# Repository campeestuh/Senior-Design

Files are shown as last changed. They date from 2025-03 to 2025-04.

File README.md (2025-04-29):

Circuit Wiring:

Rotary Encoder   --> FREENOVE ESP32 WROOM
> CLK (Output A) --> Pin 4 
> DT  (Output B) --> Pin 5 
> SW  (Switch)   --> Pin 16 
>  +  (VCC)      --> 5V 
> GND            --> GND

LCD 
VCC                 --> 5V
SDA (Serial Data)   --> Pin 21
SCL (Serial Clock)  --> Pin 22
GND                 --> GND

Button 
GND    --> GND
Signal --> Pin 19

Harness
STEP/PUL    --> Pin 15
DIRECTION   --> Pin 16
ENABLE      --> 5V

AUGER 
STEP/PUL    --> Pin 13
DIRECTION   --> Pin 14
ENABLE      --> 5V

AUGER 2 
STEP/PUL    --> Pin 33
DIRECTION   --> Pin 32
ENABLE      --> 5V

TREADMILL
STEP/PUL    --> Pin 27
DIRECTION   --> Pin 25
ENABLE      --> 5V

Arduino IDE
Board: ESP32 Wrover Module
How to get ESP32 Board Support:
- Go to File > Preferences
- In "Additional Board Manager URLs" add this URL:
https://dl.espressif.com/dl/package_esp32_index.json
- Click OK and save
- 
Install LiquidCrystal Library by Adafruit

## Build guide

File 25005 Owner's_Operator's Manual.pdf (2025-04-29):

# Owner’s/Operator’s Manual for Rat Treadmill

### Instructions for Use, Maintenance, and Safety

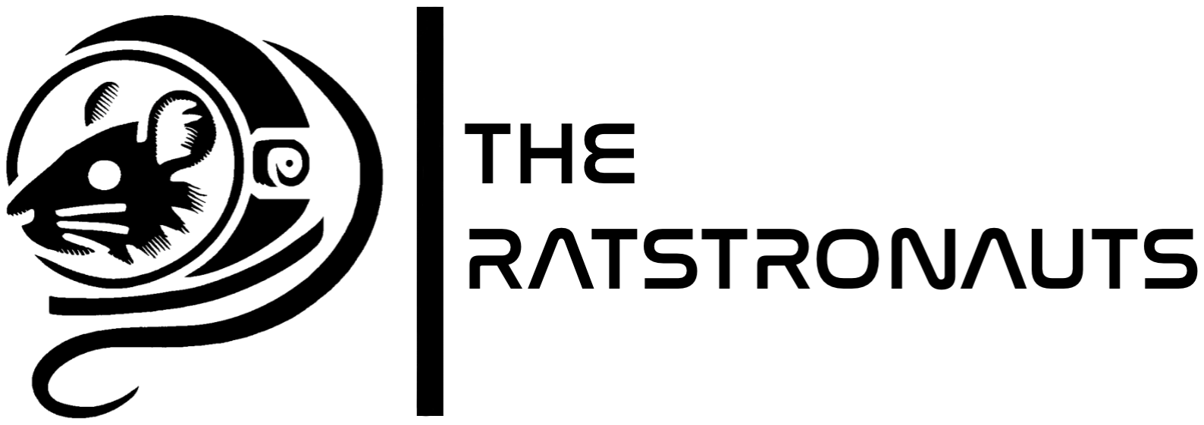
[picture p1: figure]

### Revision C

### Date of Issue: 05/07/2025

### Table of Contents

1. Introduction | 3
2. Safety Guidelines | 4
3. System Components | 7
4. Installation and Setup | 8
5. Operating Instructions | 10
6. Maintenance and Cleaning | 11
7. Technical Specifications | 16
8. Appendices | 17
9. Glossary | 18
10. Revision History | 19

### 1. Introduction

Welcome to the Owner’s/Operator’s Manual for the Rat Treadmill, a specialized research device designed to facilitate controlled exercise and locomotion studies in laboratory rodents. This treadmill’s advanced harness system, adjustable belt speed, and integrated data collection features enable researchers to study a range of physiological and behavioral parameters under standardized, reproducible conditions. Whether you are investigating muscle function, bone density changes, or aerobic capacity, the Rat Treadmill is engineered to help you gather accurate and consistent data while maintaining high standards of animal welfare.

This manual provides comprehensive guidance on setting up, operating, and maintaining the Rat Treadmill to ensure optimal performance and reliability. You will find safety instructions, technical specifications, and best practices for routine and preventative maintenance. Adherence to these guidelines not only helps protect the animals and operators but also contributes to the integrity and repeatability of your research findings.

By familiarizing yourself with the contents of this manual, you will gain an understanding of:

1. Safe Operation: Essential safety measures to protect both lab personnel and animals, including correct harness usage and emergency stop procedures.
2. Installation and Setup: Step-by-step instructions on how to calibrate and prepare the treadmill for use.
3. Daily Use and Study Protocols: Best practices for monitoring the animal’s condition and adjusting exercise parameters
4. Maintenance and Troubleshooting: Guidelines for regular cleaning, inspection, and repairs to maintain accuracy, prolong the lifespan of the equipment, and reduce downtime.

Please read this manual thoroughly before using the Rat Treadmill and keep it readily available for reference. Together, we can uphold the highest standards of care, safety, and scientific rigor in every research endeavor.

### 2. Safety Guidelines

- General Safety Reminder
- Although the Rat Treadmill is designed for ease of operation, safety must remain a priority. Only handle the treadmill by the areas that are color-coded in blue, as these sections are specifically intended for user interaction. Avoid touching or bypassing any other parts—particularly those marked with warning labels or guarded compartments—while the device is running. If you need to load or handle the aggregate, use a suitable respirator to protect against airborne particles and use the treadmill in a suitable environment. Always power down and wait for all motion to stop before clearing any obstructions or performing any maintenance tasks.
- Warnings and Precautions
- Proper Harness Use: Always ensure the harness is correctly fitted to the animal before operation. A loose or poorly adjusted harness can lead to injury or compromised research data. If in doubt, consult the harness fitting guidelines in this manual.
- Preventing Aerosolization of Regolith: Handle regolith gently and within a fume hood to minimize dust generation. A fume hood is required for usage of the system with aggregate. Avoid shaking, pouring, or dumping regolith in a way that creates airborne particles.
- Emergency Stop and Safety Features
- Unlike many traditional machines, the Rat Treadmill’s emergency stop (E-stop) feature initiates a gradual deceleration rather than an immediate halt. This prevents sudden jolts or stress on the rat, helping maintain its well-being during unexpected stops. Once the E-stop is engaged, the harness system automatically lifts the rat slightly above the belt and then sets the rat back down, ensuring the animal is safely out of contact with any moving parts.
- To further protect users and animals, all approved interaction points are color-coded in blue. Areas prone to pinch or crush injuries are equipped with warning decals and protective grates/covers, discouraging contact with moving mechanisms. Always avoid reaching into any section not marked in blue, and do not bypass guards or safety covers.
- Warning Decals (ISO 7010)
- P015 – No reaching in

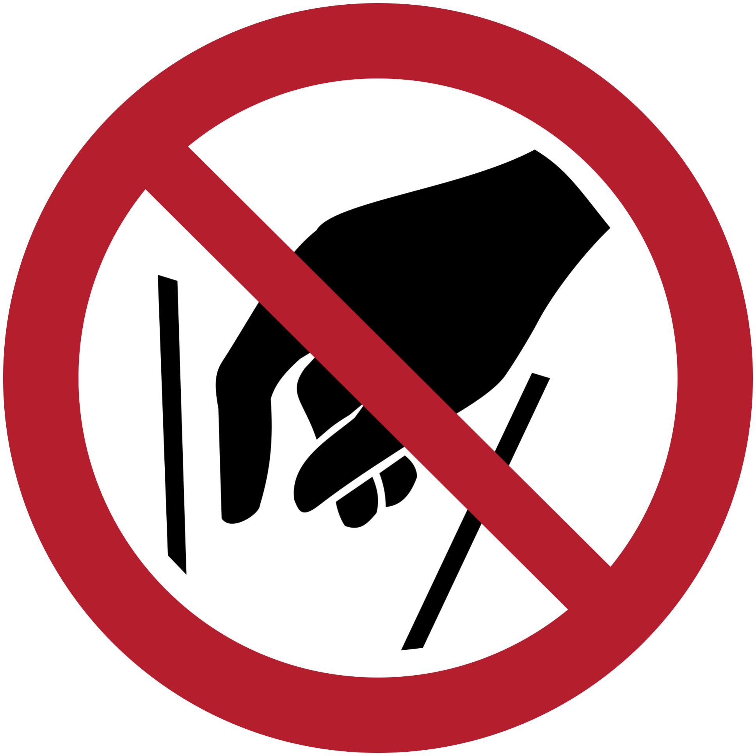
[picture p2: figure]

- Aggregate used in the treadmill may collect or clump in the hoppers, especially during heavy or prolonged use. While it might be tempting to manually guide or clear these accumulations, doing so places hands and fingers at risk of being trapped or pinched by the moving mechanical components.
- Do not insert hands, fingers, or tools into the hopper area while the treadmill is running. Always power down the treadmill before attempting any maintenance or cleaning.
- If you observe a clog or excessive buildup of aggregate, refer to the “Maintenance and Cleaning” section of this manual for instructions on safely clearing the blockage.
- P016 – Do not spray with water

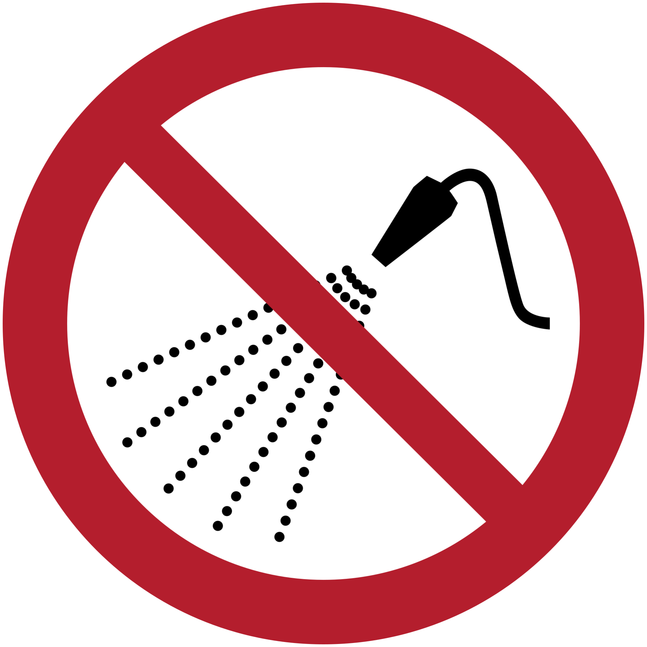
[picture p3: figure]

- Spraying or misting water can cause the aggregate to clump, disrupting the treadmill’s functionality and potentially damaging seals, leading to mechanical failure.
- Do not spray or apply water in or around the treadmill. Keeping the system dry is essential to maintain proper operation and prolong equipment life.
- If dust generation is a concern, operate the treadmill inside a fume hood. This ensures both operator safety and the prevention of moisture-related damage to the system.
- W024 – Crushing of hands/Danger of crush injuries

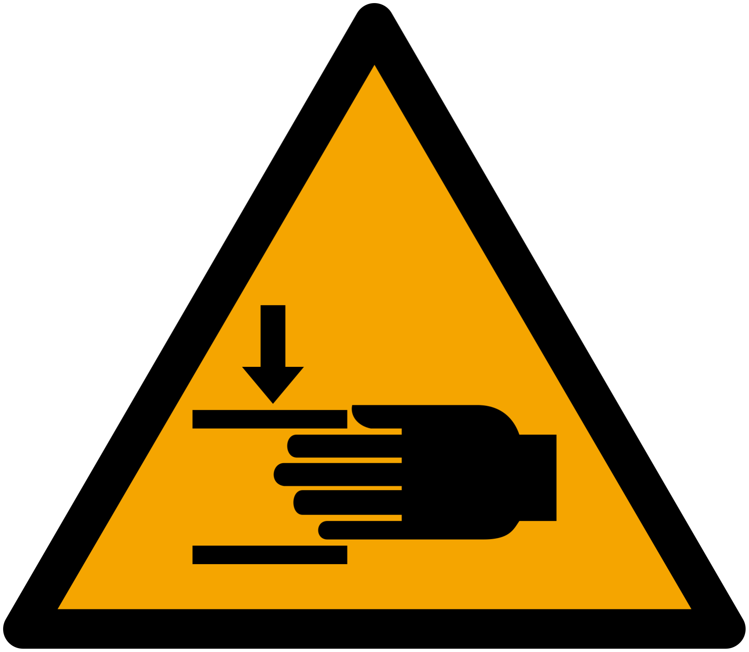
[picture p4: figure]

- The continuous motion of the treadmill belt and other internal mechanisms can pinch, crush, or entangle hands and fingers if they come into contact with these areas while the system is operational.
- Do not touch or reach into the belt area or any moving components while the treadmill is running. Always ensure the treadmill is powered off and fully stopped before performing any cleaning, adjustments, or maintenance tasks.
- If foreign objects fall onto the belt or inside the treadmill, Shut Down the unit and wait until all moving parts come to a complete stop before carefully removing them. Keep all guards, covers, and safety features in place to help prevent accidental contact. If there is an emergency, refer to “Emergency Stops” in “Operating Instructions”

### 3. System Components

- Treadmill Overview

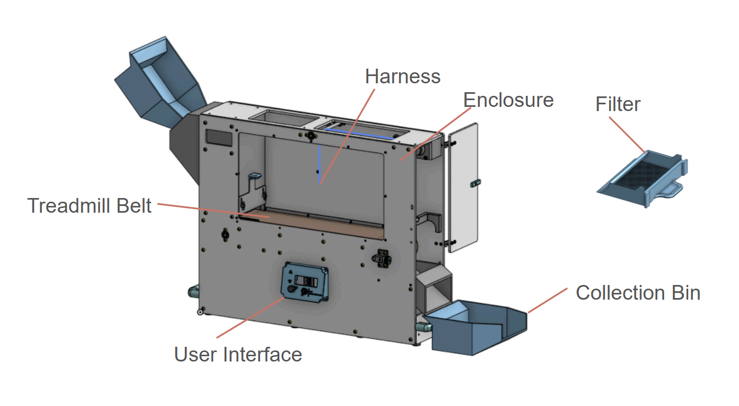
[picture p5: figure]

- Key Components
- Harness - suspends the rat to create a synthetic reduced gravity.
- Belt - Surface that aggregate is placed on to create an ambulatory surface
- Waste Filter - Collects rat waste to prevent recirculation
- User Interface - allows user to interact with and control the system
- Enclosure - ties the subsystems together and encloses the space for the Rat.
- Collection Bin - Collects aggregate for recirculation.

### 4. Installation and Setup

- Inspection
- Check for Damage or Missing Parts
Inspect for visible damage or missing components. Ensure all parts match those listed in the “Parts List” section of this manual.

- Inspect the GT2 Belts (Behind Clear Covers)
Locate and visually check the GT2 drive belts behind the clear covers. Confirm they are free from cracks, tears, or misalignment. If a belt appears damaged or excessively loose refer to the “Maintenance” section for replacement and tensioning instructions.
- Check the Treadmill Belt Alignment
Before powering on, confirm the treadmill belt runs true (i.e., it does not drift to one side). If the belt is off-center, refer to the “Troubleshooting” or “Maintenance” sections for alignment and tension adjustment procedures.
- Check for Potential Jams
Carefully examine the belt, hoppers, and any visible moving parts for obstructions. If you notice foreign objects or misaligned components, remove or correct them before using the treadmill.
○
- Placement Requirements
- Fume Hood or Tabletop Use
■ For Experiments with Aggregate: Place the treadmill inside a fume hood to help extract any aerosolized dust and maintain a safe working environment.
■ For Experiments without Aggregate: You may safely position the treadmill on a sturdy table capable of supporting its weight and operation.
- Clearance and Ventilation
■ Allow for 900 × 400 × 600 mm (L × W × H) [ 35.4" × 15.7" × 23.6] of clear space around the device to ensure smooth operation, with a preferred clearance of 1400 × 650 × 660 mm (55.12 in × 25.59 in × 25.98 in) if possible.
■ If you are using a fume hood, position the top of the treadmill to align with the hood’s exhaust for optimal dust extraction and airflow.
- Initial Calibration
■ Belt Tensioning
Before first use, confirm that the treadmill belt is properly tensioned. This helps prevent slippage, ensures consistent speed, and prolongs belt life. Refer to the “Maintenance” or “Troubleshooting” sections for specific tensioning instructions.
- Testing Aggregate Circulation
If you will run tests involving aggregate, perform a brief dry run to observe aggregate flow and check for clogging or uneven distribution. Make any necessary adjustments before conducting formal experiments.

### 5. Operating Instructions

- Starting the System
- Powering On
1. Ensure the system is clear of any debris, no animal is loaded into the system, and that the system is in an appropriate location of operation.
2. Ensure the system is plugged into 120V AC wall power.
3. Flip the green power switch on the left hand side of the enclosure
4. Disengage the emergency stop
5. You will be greeted on the screen and the system is ready for use.
- Selecting Settings (Speed, Weight Simulation)
1. Rotate the rotary encoder to select the sub menu that you desire. Once over the submenu desired, click the rotary encoder by pressing it in.
a. Weight Simulation - Use the arrow buttons to raise and lower the rat until in a desired position. Click the rotary encoder to navigate back to the main menu.
b. Speed - Use the rotary encoder to select a desired speed. Clockwise increases the speed while counter clockwise lowers the speed. To go back to the main menu, the speed must be at 0m/s. Click the rotary encoder to navigate back to the main menu.

Note: The Speed on the screen takes 1 second to update.

- Loading Aggregate
1. Load the upper hopper using the fill port on the top of the left panel and the bins.
2. Power on the treadmill as per “Powering On” instructions.
3. Run the treadmill’s speed mode.
- Removing Aggregate
1. Remove the Filter
2. Run the treadmill’s speed mode until a majority of the aggregate is removed from the system while collecting the aggregate in the bins
- Setting Aggregate Height (assuming the system is filled with aggregate)
1. Roughly estimate the height of the leveling bar
a. Loosen the blue thumbscrews.

b. Lift the leveling bar to the height desired using the blue handle.
c. Tighten the thumbscrews.

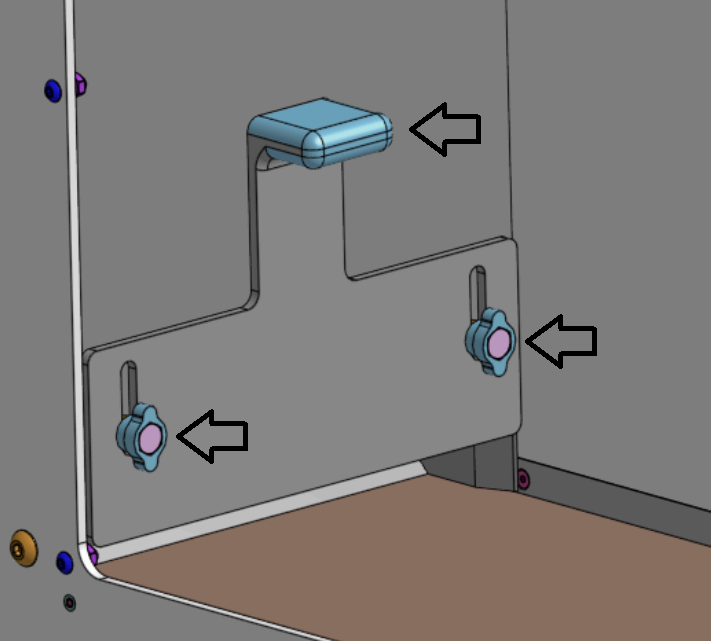
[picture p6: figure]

2. Turn on the treadmill using the powering on procedures
3. Run the treadmill for a few seconds to let the aggregate disperse through the system and add aggregate as needed per the aggregate loading instructions
4. Measure the thickness of the aggregate layer and make adjustments to the leveling bar accordingly.
- Loading the Rat
- Proper Harness Attachment
■ Refer to
https://www.lomir.com/slings/sling-suit-rodent-sling/ for harness attachment to the rat and propper usage.
- Clip the harness into the BLUE chord using the carabiner. Ensure the chord is threaded properly

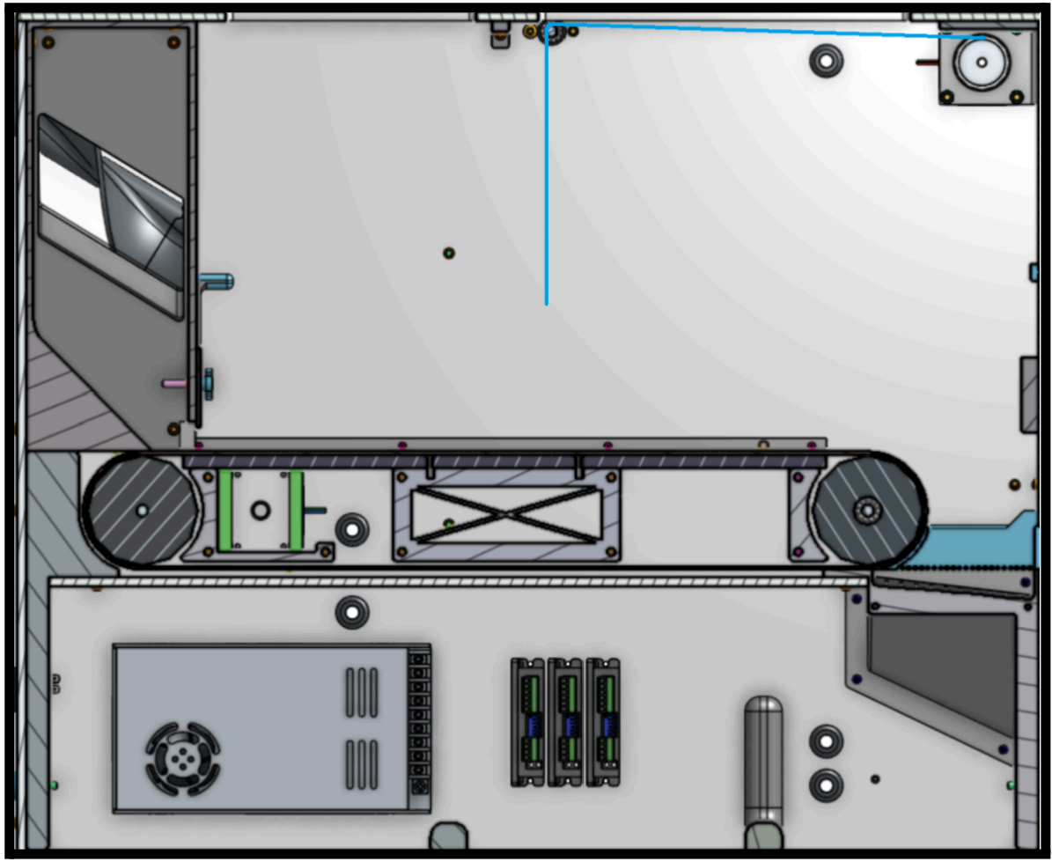
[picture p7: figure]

- Stopping the System
- Routine Stops
1. Slow the treadmill to a stop using the rotary encoder
2. Disconnect the Rat from the harness chord and remove the Rat
3. Power off the machine
- Emergency Stops
1. Press the large RED E-Stop button on the front of the machine in case of emergency.

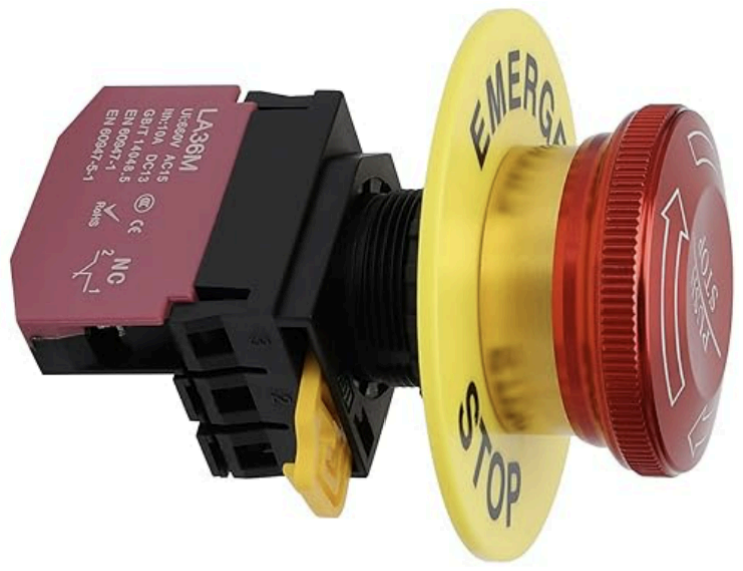
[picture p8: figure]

2. Gently remove the rat to ensure no harm is caused.
3. Power off machine then restart using the “Powering On” procedure

### 6. Maintenance and Cleaning

Maintenance:

Lubricating the Bearings

- Frequency: Check bearings monthly or as dictated by the treadmill’s usage level.
- Procedure:
1. Access Bearings: Remove covers or guards if necessary (follow instructions in “Maintenance” or “Troubleshooting” sections).
2. Apply Light Oil: Use a small amount of light machine oil on the bearings.
3. Wipe Excess: After a brief rotation to distribute lubricant, wipe away any surplus oil to prevent drip or contamination.

Treadmill Belt and Pulley Checks

- Inspection:
1. Ensure the treadmill belt is tracking correctly (running true) and has proper tension. Tightening a knob will make the belt veer away from that knob.
2. Use the blue knobs to tension the belt. It is desired to have it track as closely to the center. It should be able to move by hand, driving the motors backwards easily.
3. Inspect pulleys for visible wear or misalignment.
- Adjustment:
1. If the belt shows signs of drifting or slipping, refer to the “Belt Alignment and Tensioning” instructions in the “Troubleshooting” section.
2. Replace belts or pulleys if damage or significant wear is evident.

Harness System Inspection

- Purpose: A properly functioning harness system is essential for animal safety and data integrity.
- Procedure:
1. Visual Inspection: Look for fraying straps, worn clips, or loose stitching.
2. Attachment Points: Confirm that all clips and fasteners are secure and functioning.
3. Testing: Manually pull the harness lightly to ensure it holds steady without slipping or detaching.

Aggregate Circulation System Cleaning

- Fine Dust Buildup: Dust can accumulate in the hoppers, rollers, and the electronics compartment, potentially causing clogs, uneven flow, jamming, or electrical failure.
- Procedure:
1. Power Down and Unplug: Ensure the treadmill is off and disconnected before cleaning.
2. Open Accessible Panels:

Rollers/Beneath Belt

■ Untension the Treadmill belt
■ Remove the 23 M5x10mm Button head Screws (Yellow), the 4 M5x15mm Button Head Screws (Magenta), and the 2 M3x10mm Button Head Screws (Blue Inside green Box). Do not remove the 4 M5x10 Screws holding the tensioner on.

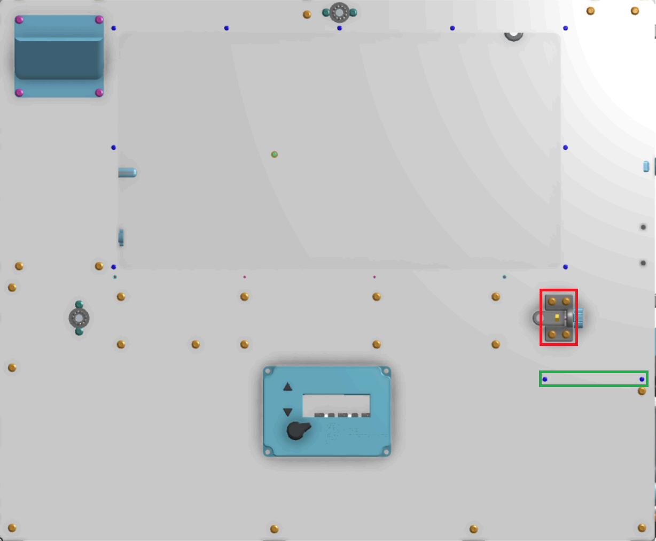
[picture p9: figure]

■ Remove the entire front panel, being cautious with the electronics. Disconnect the power to the ESP32 and the motor driver cables.
■ Clean out the build up using a vacuum, brush, etc.
■ Replace the panel ensuring to plug in the cables and that all of the rods (both rollers and the harness) are all lined up.
■ Replace and tighten all of the screws.

Electronics

■ Remove the 8 M5x15mm Button Head Screws
■ Remove the bottom panel
■ Clean out the build up using a vacuum, brush, etc.

Belt Replacement

If the treadmill belt becomes worn, frayed, or damaged, replace it promptly to maintain safe and accurate operation.

1. Untension the Treadmill belt
2. Remove the 23 M5x10mm Button head Screws (Yellow), the 4 M5x15mm Button Head Screws (Magenta), and the 2 M3x10mm Button Head Screws (Blue Inside green Box). Do not remove the 4 M5x10 Screws holding the tensioner on.
3. Remove the entire front panel, being cautious with the electronics. Disconnect the power to the ESP32 and the motor driver cables.
4. Remove the remaining screws for the upper hopper
5. Remove the Belt and replace the belt
6. Reverse the steps to assemble the system

Replacement and Tensioning Instructions for the GT2 Belts

1. Power Down and Unplug
- For safety, disconnect the treadmill from its power source before performing any maintenance on the drive system.
2. Access the Belt Area

- Remove the clear cover that protects the GT2 belt.
- Consult the exploded diagrams or parts list to identify the belt tensioning bolts or motor adjustment slots.
3. Loosen the Tensioner or Motor Mount
- Locate the 4 screws that allow the motor to slide and loosen them carefully. This will reduce tension on the belt, making it easier to adjust.
4. Adjust the Belt Tension/Replace Belt
- Pull the motor gently in the appropriate direction to increase or decrease the belt tension.
- Replace Belt if needed.
- Take care not to over-tighten the belt; excessive tension can lead to accelerated wear on bearings or belt teeth.
- Conversely, under-tension may cause slipping or skipping, especially during operation at higher loads.
5. Verify Alignment
- Ensure the GT2 belt is aligned properly with the pulley teeth. The belt should track straight across the pulleys without drifting toward the edges. Realign the motor or idler pulley if necessary.
6. Tighten the Screws
- Once you have the desired tension, securely retighten the screws.
- Double-check that the belt remains aligned and maintains the appropriate tension as you tighten.
7. Test Run
- Reinstall the clear cover(s).
- Restore power and perform a brief test run at a low speed to confirm smooth, reliable operation.
- Listen for unusual noise or clicking, which can indicate excessive tension or belt misalignment.
8. Re-check After Initial Use
- After several test runs or one full session, re-check belt tension and alignment. Minor readjustments might be necessary as the belt wears in or settles into position.

Cleaning Instructions

Disinfecting the Belt and Harness

- Frequency: After each experimental run or whenever contamination is suspected.
- Procedure:

1. Mild Disinfectant: Use a lab-approved disinfectant that does not compromise materials (e.g., soap-water solution for the belt material).
2. Soak and Wipe: Apply disinfectant with a cloth, not by spraying. Thoroughly wipe belt and harness surfaces.
3. Allow to Dry: Ensure everything is fully dry before reassembling or using again.

Wiping Down Plastic Sides and Components

- Important: Do not use alcohol-based wipes on the clear acrylic window, as this can cause clouding and/or cracking over time.
- Approved Surfaces: White HDPE surfaces and black/blue PETG parts tolerate cleaners and alcohol-based wipes well.
- Procedure:
1. Use a Non-Abrasive Cloth: Microfiber or soft lint-free cloths are recommended.
2. Use Appropriate Cleaning Agent: Water with mild soap or an approved cleaner for acrylic/PETG/HDPE.
3. Gentle Pressure: Avoid scrubbing aggressively to prevent scratches or surface damage.

Empty Waste Collection Tray

- Open Door
- Remove tray and dispose of waste

Troubleshooting

Common Issues and Resolutions

- Belt Motor Skipping
- Possible Cause: Motor belt tension is too loose, or the GT2 drive belt is worn.
- Solution: Check motor belt tension, replace GT2 belt if damaged.
- Belt Tension Too High
- Possible Symptoms: Excessive strain on the motor, unusual noise (motor skipping), or belt damage.
- Solution: Refer to tensioning instructions to loosen the belt slightly.
- Jam in Treadmill Belt Area
- Possible Cause: Aggregate or foreign objects stuck under belt or in rollers.
- Solution: Power down, remove obstruction, inspect belt for damage.
- GT2 Drive Belt Issues

- Possible Cause: Misaligned pulleys, worn or torn belt.
- Solution: Realign pulleys and/or replace belt following the steps in “GT2 Belt Replacement.”
- System Immediately Raising Harness When Powered On
- Cause: The emergency stop (E-stop) or fail-safe trigger may be disengaged upon startup.
- Solution: Fully engage the E-stop (release or reset), then power on as per the “Powering On” procedure.

### 7. Technical Specifications

Dimensions and Weight

- Overall Dimensions XYZ: 844.94mm × 219.16mm × 586.75mm (33.26in × 8.63in × 23.10in)
- Weight: 15.4 Kg (33.95lb)

Power Requirements

- Voltage: (110–120 V AC )
- Frequency: 60 Hz
- Power Consumption: (350 W)

Supported Weight Ranges for Simulated Gravity

- This treadmill is designed to accommodate rats weighing up to 800 grams.
- Refer to https://www.lomir.com/slings/sling-suit-rodent-sling/ for detailed guidance on selecting and installing the correct harness size for your specific animal weight range.

User Interface Features

1. Rotary Encoder
- Turn the encoder to navigate through menus on the main screen.
2. Up/Down Buttons
- Press these to adjust the rat’s position or harness height in small increments.
3. Set Position Button
- Once the desired harness height or position is reached, press this button to lock it in place.
4. Screen
- Displays current speed, harness position, error messages, and other operational data.
5. E-Stop Button
- Initiates a gradual deceleration of the treadmill rather than an immediate stop, preventing sudden jolts to the animal. Also triggers the harness to raise the rat off the belt.

Aggregate Type and Volume Guidelines

- Aggregate Type: Use regolith or aggregate that is safe with animals and that is electrically non-conductive. The maximum particle size should not exceed the sieve size being used.
- Recommended Volume: ~5kg or 5L (Assuming Clumping Litter Usage).

### 8. Revision History

- Rev A - Created Owners Manual
- Rev B - Updated Procedures, added Figures.
- Rev C - Updated to reflect design changes.

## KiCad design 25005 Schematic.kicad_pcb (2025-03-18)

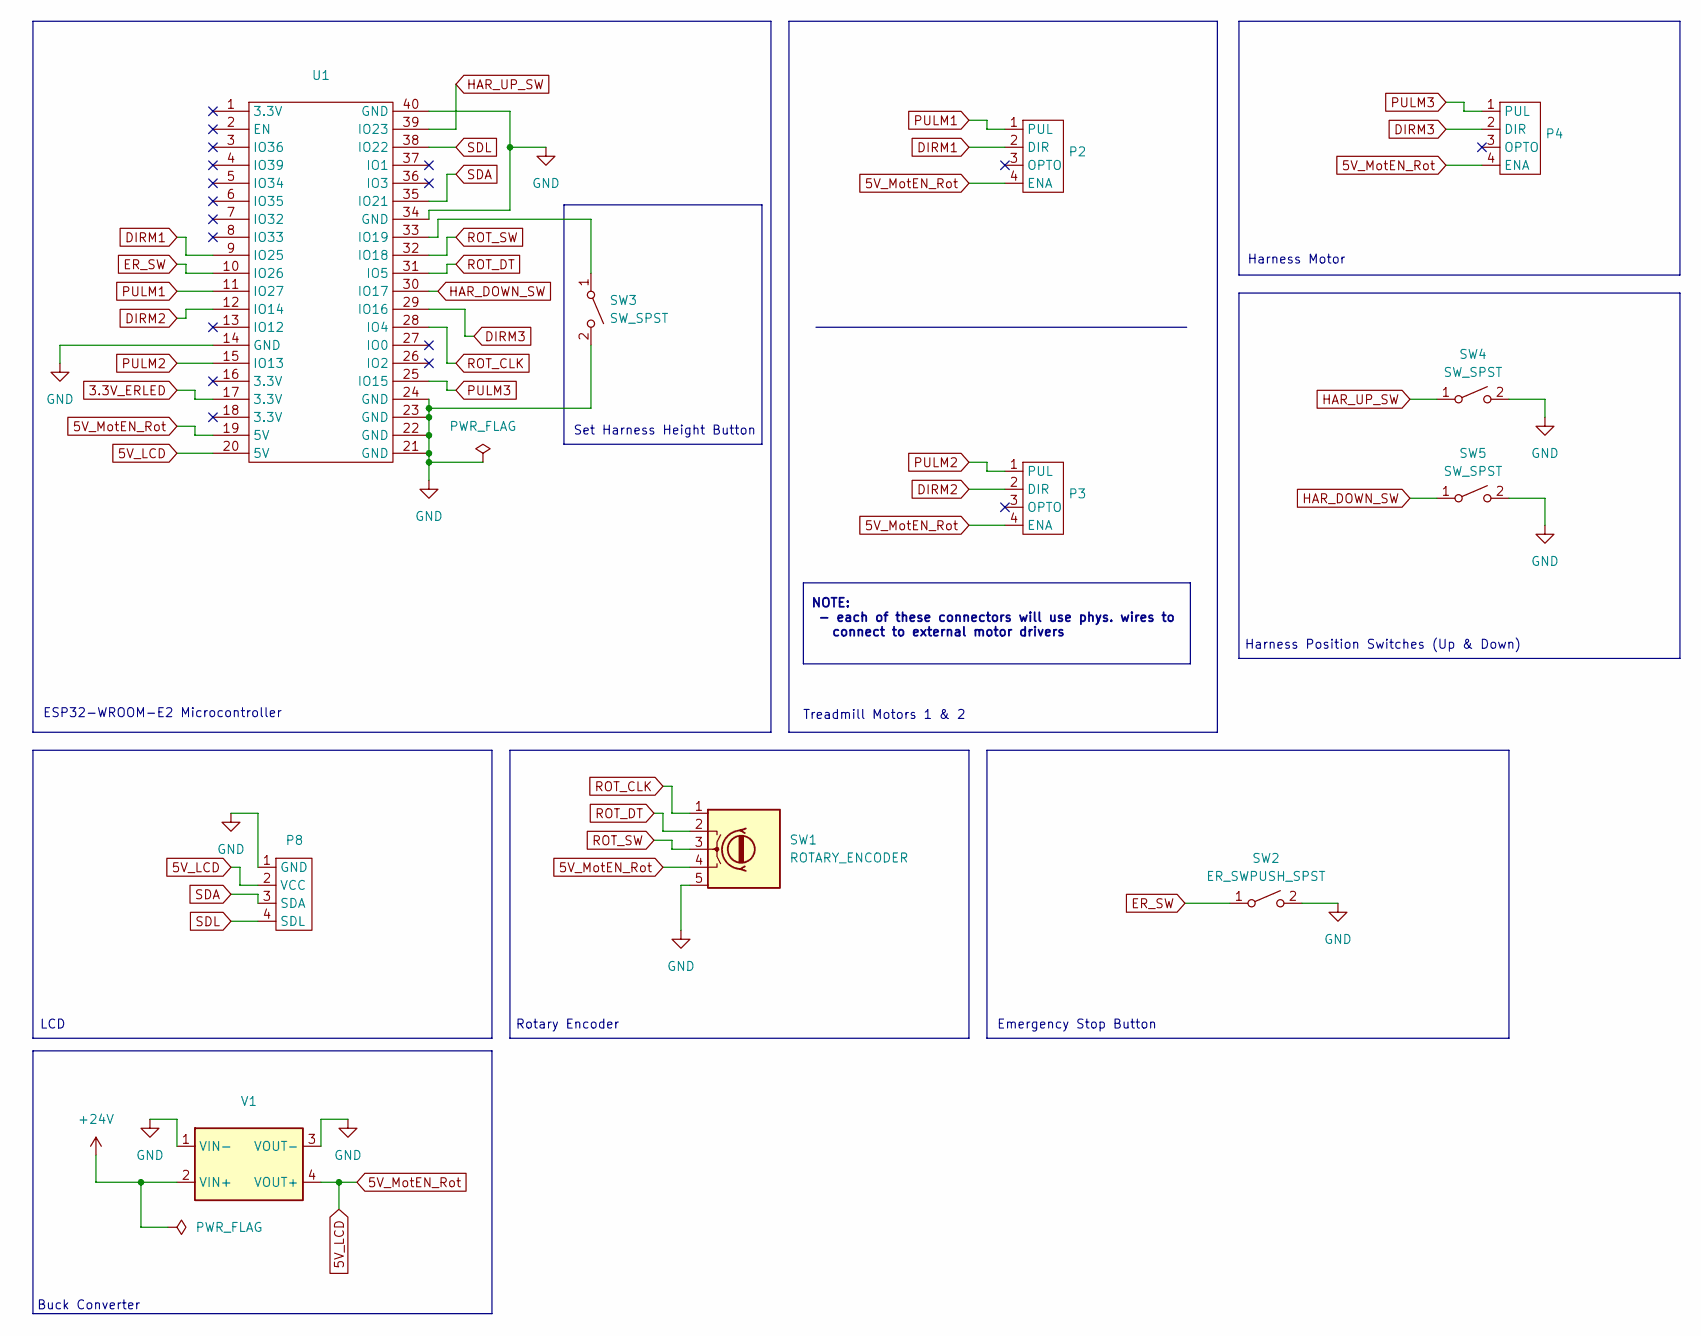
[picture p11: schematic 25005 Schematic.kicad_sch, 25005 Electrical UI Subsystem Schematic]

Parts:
P2, P3, P4: 3PIN_F_CONN_MOTORS
P8: 4PIN_F_CONN_LCD
SW1: ROTARY_ENCODER; 5PIN_F_CONN
SW2: ER_SWPUSH_SPST; ER_BUTTON
SW3, SW4, SW5: SW_SPST; SPST_SW
U1: ESP32_WROOM_32E
V1: BUCK_CONV

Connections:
3.3V_ERLED: U1.17 (3.3V)
5V_LCD: P2.4 (ENA), P3.4 (ENA), P4.4 (ENA), P8.2 (VCC), SW1.4 (5V), U1.19 (5V), U1.20 (5V), V1.4 (VOUT+)
+24V: V1.2 (VIN+)
DIRM1: P2.2 (DIR), U1.9 (IO25)
DIRM2: P3.2 (DIR), U1.12 (IO14)
DIRM3: P4.2 (DIR), U1.29 (IO16)
ER_SW: SW2.1, U1.10 (IO26)
GND: P8.1 (GND), SW1.5 (GND), SW2.2, SW3.2, SW4.2, SW5.2, U1.14 (GND), U1.21 (GND), U1.22 (GND), U1.23 (GND), U1.24 (GND), U1.34 (GND), U1.40 (GND), V1.1 (VIN-), V1.3 (VOUT-)
HAR_DOWN_SW: SW5.1, U1.30 (IO17)
HAR_UP_SW: SW4.1, U1.39 (IO23)
unnamed: SW3.1, U1.33 (IO19)
PULM1: P2.1 (PUL), U1.11 (IO27)
PULM2: P3.1 (PUL), U1.15 (IO13)
PULM3: P4.1 (PUL), U1.25 (IO15)
ROT_CLK: SW1.1 (CLK), U1.28 (IO4)
ROT_DT: SW1.2 (DT), U1.31 (IO5)
ROT_SW: SW1.3 (SW), U1.32 (IO18)
SDA: P8.3 (SDA), U1.35 (IO21)
SDL: P8.4 (SDL), U1.38 (IO22)

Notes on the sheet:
Harness Motor
ESP32-WROOM-E2 Microcontroller
Rotary Encoder
NOTE: - each of these connectors will use phys. wires to connect to external motor drivers
Set Harness Height Button
Harness Position Switches (Up & Down)
Emergency Stop Button
Treadmill Motors 1 & 2
Buck Converter
LCD

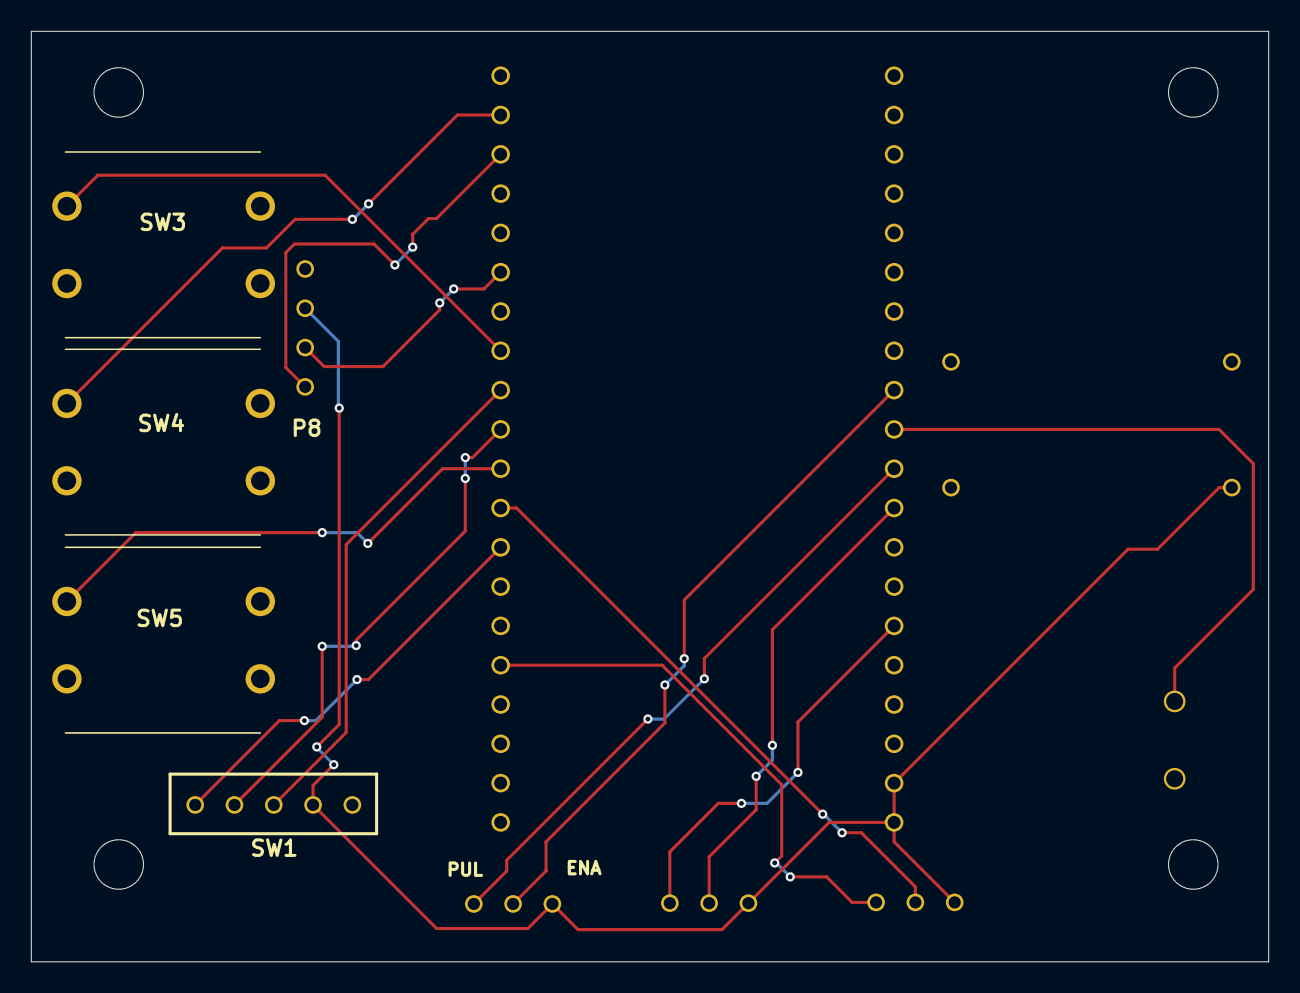
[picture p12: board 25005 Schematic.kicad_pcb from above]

Board: 2 copper layers, 80.0 x 60.1 mm, 11 parts (1 on the bottom side), 17 nets.

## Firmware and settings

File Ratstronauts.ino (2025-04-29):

// Authors: Juan Campista & Alicia Enriquez     
// Date:    4/28/2024
// Summary: This code implements a rotary encoder-controlled user interface for a treadmill system
//          with two modes: speed control for treadmill & both auger motors and directional control for a harness
//          motor. It displays a menu on an I2C LCD, handles rotary input for navigation and selection,
//          and adjusts motor behavior based on user interaction. Emergency stop and directional
//          control buttons are also integrated for safety and manual overrides.
//----------------------------------------------------------------------------------------------------------------------------//
#include <LiquidCrystal_PCF8574.h> // Include library to control an LCD over I2C
#include <AccelStepper.h>           // Include library to control stepper motors
#include <esp_sleep.h>              // Include library to manage deep sleep on ESP32

// Pin Definitions
#define encoderCLK 4                // Rotary encoder CLK signal pin
#define encoderDT 5                 // Rotary encoder DT signal pin
#define rotaryButton 18             // Rotary encoder push button pin

#define treadDirectionPin 25        // Treadmill motor direction control pin
#define treadPulsePin 27            // Treadmill motor pulse (step) pin

#define augerDirectionPin 14        // Auger motor 1 direction control pin
#define augerPulsePin 13            // Auger motor 1 pulse (step) pin

#define auger2DirectionPin 32       // Auger motor 2 direction control pin
#define auger2PulsePin 33           // Auger motor 2 pulse (step) pin

#define harnessPulsePin 15          // Harness motor pulse (step) pin
#define harnessDirectionPin 16      // Harness motor direction control pin

#define Button 29                   // General-purpose button pin
#define emergencyButton 26          // Emergency stop button pin
#define clockwiseButton 17          // Button to move harness clockwise
#define counterclockwiseButton 23   // Button to move harness counterclockwise

// LCD Settings
const int lcdColumns = 16, lcdRows = 2;        // LCD display dimensions
LiquidCrystal_PCF8574 lcd(0x27);               // Create LCD object at I2C address 0x27

// Treadmill Settings
AccelStepper treadmill(1, treadPulsePin, treadDirectionPin); // Create treadmill stepper motor object
int treadmillSpeed = 0;                       // Current treadmill speed
const int maxSpeed = 1337;                     // Maximum treadmill speed
const int treadmillIncrement = 17;             // Increment to adjust treadmill speed

// Auger Settings
AccelStepper auger(1, augerPulsePin, augerDirectionPin); // Create auger 1 stepper motor object
int augerSpeed = 0;                          // Current auger speed
const int augerMaxSpeed = 2044;               // Maximum auger speed
const int augerIncrement = 26;                // Increment to adjust auger speed

// 2nd Auger (mirrors auger1)
AccelStepper auger2(1, auger2PulsePin, auger2DirectionPin); // Create auger 2 stepper motor object

// Harness Motor Settings
AccelStepper harness(1, harnessPulsePin, harnessDirectionPin); // Create harness stepper motor object
bool positionSaved = false;                  // Track if harness position was saved
int setPosition = 0;                          // Position value to save for harness
bool eButtonPressed = false;                  // Track emergency button pressed state
unsigned long lastMoveTime = 0;                // Timestamp of last movement
int count = 0;                                 // General purpose counter

// Menu Variables
enum Mode { MENU, SPEED_MODE, HARNESS_MODE } currentMode = MENU; // Create modes and set default to MENU
const String menuItems[] = {"SPEED", "HARNESS"}; // Menu items for display
int menuIndex = 0;                             // Current index selected in menu
const int numMenuItems = 2;                    // Total number of menu items

// Rotary Encoder State
int lastCLKState = LOW;                        // Last state of rotary encoder CLK signal
unsigned long lastDebounceTime = 0;             // Last time a button was toggled
const unsigned long debounceDelay = 50;         // Debounce delay time in milliseconds

// Button Release Guard
bool buttonReleaseGuard = false;                // Guard flag to block button repeats
unsigned long buttonReleaseTime = 0;             // Last button release timestamp
const unsigned long buttonReleaseDelay = 200;    // Button release delay in milliseconds

int buttonState = 0;                            // State of general-purpose button
int eButtonState = 0;                           // State of emergency button

void setup() {
  Serial.begin(115200);                         // Start serial communication

  lcd.begin(lcdColumns, lcdRows);               // Initialize LCD
  lcd.setBacklight(255);                        // Turn on LCD backlight at full brightness
  displayMenu();                                // Display initial menu

  pinMode(encoderCLK, INPUT);                   // Set encoder CLK as input
  pinMode(encoderDT, INPUT);                    // Set encoder DT as input
  pinMode(rotaryButton, INPUT_PULLUP);           // Set rotary button with pull-up resistor
  pinMode(Button, INPUT_PULLUP);                 // Set general button with pull-up resistor
  pinMode(emergencyButton, INPUT_PULLUP);        // Set emergency button with pull-up resistor
  pinMode(clockwiseButton, INPUT_PULLUP);        // Set clockwise button with pull-up resistor
  pinMode(counterclockwiseButton, INPUT_PULLUP); // Set counterclockwise button with pull-up resistor

  treadmill.setMaxSpeed(maxSpeed);               // Set treadmill max speed
  treadmill.setAcceleration(2000);               // Set treadmill acceleration

  auger.setMaxSpeed(augerMaxSpeed);               // Set auger 1 max speed
  auger.setAcceleration(2000);                   // Set auger 1 acceleration

  auger2.setMaxSpeed(augerMaxSpeed);              // Set auger 2 max speed
  auger2.setAcceleration(2000);                  // Set auger 2 acceleration

  harness.setMaxSpeed(800);                      // Set harness motor max speed
  harness.setAcceleration(300);                  // Set harness motor acceleration
  harness.setSpeed(0);                           // Set harness motor speed to 0

  lastCLKState = digitalRead(encoderCLK);         // Read initial state of encoder CLK
}

void loop() {
  static Mode previousMode = MENU;               // Store previous mode

  if (currentMode == MENU) {
    if (buttonReleaseGuard && millis() - buttonReleaseTime > buttonReleaseDelay) {
      buttonReleaseGuard = false;                // Reset guard after delay
    }

    if (!buttonReleaseGuard) {
      if (previousMode != MENU) {
        lcd.clear();                             // Clear LCD if mode changed
        displayMenu();                           // Re-display menu
        previousMode = MENU;                     // Update previous mode
      }
      handleEncoderForMenu();                    // Check rotary encoder for menu
      if (buttonPressed(rotaryButton)) handleMenuSelection(); // Handle selection if button pressed
    }

    if (treadmillSpeed > 0) {
      treadmill.runSpeed();                      // Run treadmill motor
      auger.runSpeed();                           // Run auger motor 1
      auger2.runSpeed();                          // Run auger motor 2
    }
  } else if (currentMode == SPEED_MODE) {
    handleSpeedMode();                           // Handle speed adjustments
    if (treadmillSpeed && augerSpeed == 0) {
      if (buttonPressed(rotaryButton)) returnToMenu(); // Return if button pressed
    }
  } else if (currentMode == HARNESS_MODE) {
    handleHarnessMode();                         // Handle harness motor control
    if (buttonPressed(rotaryButton)) returnToMenu(); // Return if button pressed
  }
}

void handleEncoderForMenu() {
  int currentCLKState = digitalRead(encoderCLK);  // Read current CLK state
  if ((millis() - lastDebounceTime) > debounceDelay && currentCLKState != lastCLKState) {
    if (digitalRead(encoderDT) != currentCLKState) {
      menuIndex++;                               // Scroll menu forward
    } else {
      menuIndex--;                               // Scroll menu backward
    }
    menuIndex = constrain(menuIndex, 0, numMenuItems - 1); // Constrain within bounds
    displayMenu();                               // Update LCD menu display
    lastCLKState = currentCLKState;               // Save current state
    lastDebounceTime = millis();                  // Update debounce timer
  }
}

void handleMenuSelection() {
  lcd.clear();                                   // Clear LCD
  lcd.print(menuItems[menuIndex] + " SELECTED"); // Show selection
  Serial.println(menuItems[menuIndex] + " SELECTED"); // Print to serial
  delay(1000);                                   // Pause

  if (menuIndex == 0) {
    currentMode = SPEED_MODE;                    // Switch to Speed mode
    lcd.clear();
    lcd.print("Speed Mode");                     // Display "Speed Mode"
    treadmill.setSpeed(treadmillSpeed);           // Set treadmill speed
  } else if (menuIndex == 1) {
    currentMode = HARNESS_MODE;                  // Switch to Harness mode
    lcd.clear();
    lcd.print("Harness Mode");                   // Display "Harness Mode"
  }
}

void displayMenu() {
  lcd.clear();                                   // Clear LCD
  lcd.setCursor(0, 0);
  lcd.print("MENU");                             // Print "MENU"
  lcd.setCursor(0, 1);
  lcd.print(menuIndex == 0 ? "-> SPEED" : "-> HARNESS"); // Show selected menu item
}

bool buttonPressed(int pin) {
  if (digitalRead(pin) == LOW && (millis() - lastDebounceTime) > debounceDelay) {
    lastDebounceTime = millis();                  // Update debounce
    return true;                                  // Return true if button pressed
  }
  return false;                                   // Else return false
}

void handleSpeedMode() {
  static unsigned long lastEncoderMoveTime = 0;   // Last encoder move time
  static bool speedDisplayed = false;             // Track if speed shown
  const unsigned long displayDelay = 1000;        // Delay before showing speed
  float linearSpeed;                              // Store calculated linear speed
  int currentCLKState = digitalRead(encoderCLK);  // Read current CLK state

  if (currentCLKState != lastCLKState) {
    if (digitalRead(encoderDT) != currentCLKState) {
      treadmillSpeed += treadmillIncrement;       // Increase treadmill speed
      augerSpeed += augerIncrement;                // Increase auger speed
    } else {
      treadmillSpeed -= treadmillIncrement;       // Decrease treadmill speed
      augerSpeed -= augerIncrement;                // Decrease auger speed
    }

    treadmillSpeed = constrain(treadmillSpeed, 0, maxSpeed); // Constrain speed
    augerSpeed = constrain(augerSpeed, 0, augerMaxSpeed);     // Constrain speed

    treadmill.setSpeed(-treadmillSpeed);           // Update treadmill speed (negative direction)
    auger.setSpeed(augerSpeed);                    // Update auger 1 speed
    auger2.setSpeed(augerSpeed);                   // Update auger 2 speed

    // Calculate RPM and linear speed
    float rpm = (abs(treadmillSpeed) * 60.0) / 400.0;
    linearSpeed = (rpm * 0.0762 * PI) / 60.0;      // Convert to m/s
    Serial.println(linearSpeed);                   // Print speed

    lastCLKState = currentCLKState;
    lastEncoderMoveTime = millis();
    speedDisplayed = false;
  }

  treadmill.runSpeed();                            // Run treadmill motor
  auger.runSpeed();                                // Run auger 1 motor
  auger2.runSpeed();                               // Run auger 2 motor

  eButtonState = digitalRead(emergencyButton);     // Read emergency button

  if (eButtonState == HIGH) {
    eButtonPressed = false;                        // Reset emergency pressed flag
  }
  if (eButtonState == HIGH) {
    eStopProcedure();                              // Start emergency procedure
  }

  if ((millis() - lastEncoderMoveTime > displayDelay) && !speedDisplayed) {
    lcd.setCursor(0, 1);
    lcd.print("Speed: ");
    lcd.print(linearSpeed, 2);                     // Display speed on LCD
    lcd.print(" m/s     ");
    speedDisplayed = true;
  }
  if (treadmillSpeed == 0 && augerSpeed == 0) {
    if (buttonPressed(rotaryButton)) returnToMenu();
  }
}

void handleHarnessMode() {
  eButtonState = digitalRead(emergencyButton); // Read emergency button state
  if (eButtonState == HIGH) eButtonPressed = false; // Reset emergency button flag if pressed

  if (digitalRead(clockwiseButton) == LOW) { // If clockwise button is pressed
    harness.setSpeed(200); // Set harness motor speed positive
    harness.runSpeed(); // Run harness motor
  } else if (digitalRead(counterclockwiseButton) == LOW) { // If counterclockwise button is pressed
    harness.setSpeed(-200); // Set harness motor speed negative
    harness.runSpeed(); // Run harness motor
  } else {
    harness.setSpeed(0); // Stop harness motor if no button is pressed
  }

  harness.runSpeed(); // Continue running harness motor
}

void eStopProcedure() {
    eButtonPressed = true; // Set emergency button flag true

    // Start harness movement without blocking execution
    harness.setMaxSpeed(800); // Set harness max speed
    harness.setAcceleration(300); // Set harness acceleration

    if (positionSaved) { // If a saved position exists
        harness.moveTo(setPosition); // Move harness to saved position
        harness.runToPosition(); // Block until position reached
    } else {
        harness.moveTo(harness.currentPosition() - 200); // Move harness backwards by 200 steps
    }

    // Keep treadmill & augers running during harness movement
    treadmill.setAcceleration(300); // Set treadmill acceleration
    auger.setAcceleration(300); // Set auger 1 acceleration
    auger2.setAcceleration(300); // Set auger 2 acceleration

    int currentTreadmillSpeed = treadmillSpeed; // Save current treadmill speed
    int currentAugerSpeed = augerSpeed; // Save current auger 1 speed
    int currentAuger2Speed = augerSpeed; // Save current auger 2 speed

    treadmill.setSpeed(-currentTreadmillSpeed); // Set treadmill speed negative
    auger.setSpeed(currentAugerSpeed); // Set auger 1 speed
    auger2.setSpeed(currentAuger2Speed); // Set auger 2 speed

    // Timing-based gradual deceleration while stepper is moving
    unsigned long lastUpdate = millis(); // Record current time
    int decelStep = 10; // Treadmill deceleration step size
    int updateInterval = 30; // Time interval between speed updates
    int augDec = 20; // Auger deceleration step size

    while ((currentTreadmillSpeed > 0 || currentAugerSpeed > 0 || currentAuger2Speed > 0) || harness.distanceToGo() != 0) {
        if (millis() - lastUpdate >= updateInterval) { // Check if time to update
            lastUpdate = millis(); // Update last time marker
            
            if (currentTreadmillSpeed > 0) { // If treadmill still moving
                currentTreadmillSpeed = max(0, currentTreadmillSpeed - decelStep); // Decrease treadmill speed
                treadmill.setSpeed(-currentTreadmillSpeed); // Update treadmill speed
            }
            if (currentAugerSpeed > 0) { // If auger 1 still moving
                currentAugerSpeed = max(0, currentAugerSpeed - augDec); // Decrease auger 1 speed
                auger.setSpeed(currentAugerSpeed); // Update auger 1 speed
            }
            if (currentAuger2Speed > 0) { // If auger 2 still moving
                currentAuger2Speed = max(0, currentAuger2Speed - augDec); // Decrease auger 2 speed
                auger2.setSpeed(currentAuger2Speed); // Update auger 2 speed
            }
        }

        // Run all motors while decelerating
        treadmill.runSpeed(); // Run treadmill
        auger.runSpeed(); // Run auger 1
        auger2.runSpeed(); // Run auger 2
        harness.run(); // Run harness motor (non-blocking)
    }

    // Stop treadmill and augers completely
    treadmill.setSpeed(0); // Set treadmill speed to 0
    auger.setSpeed(0); // Set auger 1 speed to 0
    auger2.setSpeed(0); // Set auger 2 speed to 0
    treadmill.runSpeed(); // Run treadmill
    auger.runSpeed(); // Run auger 1
    auger2.runSpeed(); // Run auger 2

    harness.moveTo(harness.currentPosition() + 200); // Move harness forward 200 steps
    while (harness.distanceToGo() != 0) { // Wait until movement done
        harness.run(); // Run harness
    }

    // System shutdown message
    Serial.println("EMERGENCY STOP COMPLETE - ENTERING LOW POWER MODE"); // Print shutdown message
    lcd.clear(); // Clear LCD
    lcd.setCursor(0, 0); // Set cursor at first row
    lcd.print("SYSTEM SHUTDOWN"); // Display "System Shutdown"
    lcd.setCursor(0, 1); // Set cursor at second row
    lcd.print("RESTART REQUIRED"); // Display "Restart Required"
    
    delay(5000); // Wait 5 seconds
    esp_sleep_enable_ext0_wakeup(GPIO_NUM_0, 0); // Configure ESP32 to wake up on GPIO0 LOW
    esp_deep_sleep_start(); // Enter deep sleep mode
}

void returnToMenu() {
  currentMode = MENU; // Switch mode back to MENU
  buttonReleaseGuard = true; // Activate button release guard
  buttonReleaseTime = millis(); // Save current time for guard
  positionSaved = false; // Clear saved position flag
  eButtonPressed = false; // Clear emergency button flag
  lcd.clear(); // Clear LCD
  displayMenu(); // Display main menu
  Serial.println("Returned to MENU"); // Print return message
}

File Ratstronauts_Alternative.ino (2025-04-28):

// Authors: Juan Campista & Alicia Enriquez     
// Date:    4/23/2024
// Summary: This code implements a rotary encoder-controlled user interface for a treadmill system
//          with two modes: speed control for a treadmill motor and directional control for a harness
//          motor. It displays a menu on an I2C LCD, handles rotary input for navigation and selection,
//          and adjusts motor behavior based on user interaction. Emergency stop and directional
//          control buttons are also integrated for safety and manual overrides.
//---------------------------------------------------------------------------------------------------------//
#include <LiquidCrystal_PCF8574.h>          // Include the library for controlling an I2C LCD
#include <AccelStepper.h>                   // Include the library for controlling stepper motors
#include <esp_sleep.h>                      // Include the library for ESP32 sleep functions

// Pin Definitions
#define encoderCLK 4                        // Rotary encoder CLK pin
#define encoderDT 5                         // Rotary encoder DT pin
#define rotaryButton 18                     // Rotary encoder push button pin

#define treadDirectionPin 25                // Direction control pin for treadmill motor
#define treadPulsePin 27                    // Step (pulse) control pin for treadmill motor

#define harnessPulsePin 15                  // Step (pulse) control pin for harness motor
#define harnessDirectionPin 16             // Direction control pin for harness motor

#define Button 29                           // General-purpose button (not yet used)
#define emergencyButton 26                  // Emergency stop button pin
#define clockwiseButton 17                  // Button to move harness clockwise
#define counterclockwiseButton 23          // Button to move harness counterclockwise

// LCD Settings
const int lcdColumns = 16, lcdRows = 2;     // LCD dimensions (16 columns, 2 rows)
LiquidCrystal_PCF8574 lcd(0x27);           // Create LCD object with I2C address 0x27

// Treadmill Settings
AccelStepper treadmill(1, treadPulsePin, treadDirectionPin); // Create treadmill stepper object
int treadmillSpeed = 0;                     // Current speed of treadmill
const int maxSpeed = 1337;                  // Maximum speed for treadmill
const int treadmillIncrement = 17;          // Increment/decrement value for treadmill speed

// Harness Motor Settings
AccelStepper harness(1, harnessPulsePin, harnessDirectionPin); // Create harness stepper object
bool positionSaved = false;                // Flag for saved harness position
int setPosition = 0;                        // Target position for harness (not used in this version)
bool eButtonPressed = false;               // Flag for emergency button state
unsigned long lastMoveTime = 0;            // Last time harness moved (not used in this version)
int count = 0;                              // Counter for rotary changes (not used in this version)

// Menu Variables
enum Mode { MENU, SPEED_MODE, HARNESS_MODE } currentMode = MENU; // Mode state
const String menuItems[] = {"SPEED", "HARNESS"}; // Menu options
int menuIndex = 0;                          // Current index in menu
const int numMenuItems = 2;                // Total number of menu items

// Rotary Encoder State
int lastCLKState = LOW;                    // Last known state of encoder CLK
unsigned long lastDebounceTime = 0;        // Last debounce time
const unsigned long debounceDelay = 50;    // Debounce delay in milliseconds

// Button Release Guard
bool buttonReleaseGuard = false;           // Prevents button re-triggering
unsigned long buttonReleaseTime = 0;       // Time when button was released
const unsigned long buttonReleaseDelay = 200; // Delay before button can trigger again

int buttonState = 0;                        // Current button state (not used in this version)
int eButtonState = 0;                       // Current emergency button state

void setup() {
  Serial.begin(115200);                     // Initialize serial communication

  lcd.begin(lcdColumns, lcdRows);          // Initialize the LCD
  lcd.setBacklight(255);                   // Set LCD backlight to max
  displayMenu();                            // Show the main menu on LCD

  pinMode(encoderCLK, INPUT);              // Set encoder CLK pin as input
  pinMode(encoderDT, INPUT);               // Set encoder DT pin as input
  pinMode(rotaryButton, INPUT_PULLUP);     // Set rotary button pin as input with pull-up
  pinMode(Button, INPUT_PULLUP);           // Set general button pin as input with pull-up
  pinMode(emergencyButton, INPUT_PULLUP);  // Set emergency button as input with pull-up
  pinMode(clockwiseButton, INPUT_PULLUP);  // Set clockwise button as input with pull-up
  pinMode(counterclockwiseButton, INPUT_PULLUP); // Set counterclockwise button as input with pull-up

  treadmill.setMaxSpeed(maxSpeed);         // Set maximum treadmill speed
  treadmill.setAcceleration(2000);         // Set treadmill acceleration

  harness.setMaxSpeed(800);                // Set maximum harness speed
  harness.setAcceleration(300);            // Set harness acceleration
  harness.setSpeed(0);                     // Initialize harness speed to 0

  lastCLKState = digitalRead(encoderCLK);  // Save initial encoder CLK state
}

void loop() {
  static Mode previousMode = MENU;         // Store the previous mode for LCD updates

  if (currentMode == MENU) {               // If in menu mode
    if (buttonReleaseGuard && millis() - buttonReleaseTime > buttonReleaseDelay) {
      buttonReleaseGuard = false;          // Reset button guard after delay
    }

    if (!buttonReleaseGuard) {
      if (previousMode != MENU) {          // If mode changed to menu
        lcd.clear();                       // Clear the LCD
        displayMenu();                     // Display the menu
        previousMode = MENU;               // Update previous mode
      }
      handleEncoderForMenu();              // Handle rotary input for menu
      if (buttonPressed(rotaryButton)) handleMenuSelection(); // If button pressed, select menu item
    }

    if (treadmillSpeed > 0) {              // If treadmill is running
      treadmill.runSpeed();                // Continue running treadmill
    }
  } else if (currentMode == SPEED_MODE) {  // If in speed adjustment mode
    handleSpeedMode();                     // Adjust speed based on encoder
    if (treadmillSpeed == 0) {
      if (buttonPressed(rotaryButton)) returnToMenu(); // Return to menu if stopped
    }
  } else if (currentMode == HARNESS_MODE) {// If in harness control mode
    handleHarnessMode();                   // Run harness motor
    if (buttonPressed(rotaryButton)) returnToMenu(); // Return to menu on button press
  }
}
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

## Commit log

2025-03-18 PCB & Schematic
    [25005 Schematic.kicad_pcb, 25005 Schematic.kicad_sch]
2025-03-20 Create SeniorDesign2
    Added 2nd Auger Motor
